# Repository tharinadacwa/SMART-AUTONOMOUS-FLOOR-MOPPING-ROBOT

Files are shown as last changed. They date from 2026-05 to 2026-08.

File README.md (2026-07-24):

<div align="center">

# SAFMR: Smart Autonomous Floor Mopping Robot

### A full-stack autonomous cleaning robot: LiDAR SLAM, Boustrophedon coverage planning, real-time stepper control, and a custom USB-C PD charging board









<br>

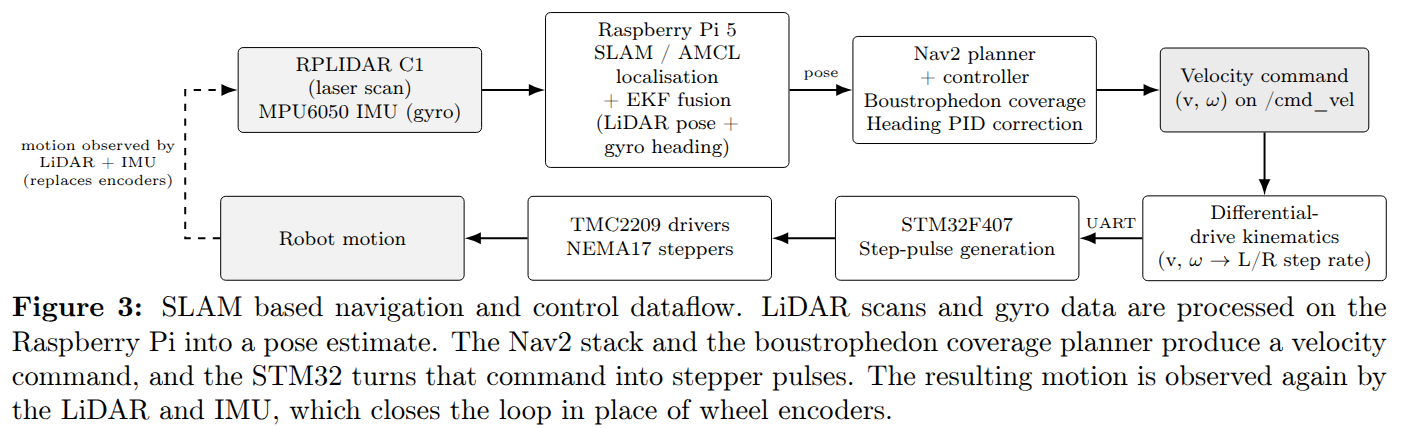
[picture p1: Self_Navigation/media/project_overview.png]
SAFMR system overview


<sub><b>Team MindFlayers</b></sub>

</div>

---

## Table of contents

- [What this is](#what-this-is)
- [The problem we set out to solve](#the-problem-we-set-out-to-solve)
- [System at a glance](#system-at-a-glance)
- [Architecture](#architecture)
- [Repository structure](#repository-structure)
- [Subsystem 1: Navigation and coverage planning](#subsystem-1-navigation-and-coverage-planning)
- [Subsystem 2: Main controller (firmware and PCB)](#subsystem-2-main-controller-firmware-and-pcb)
- [Subsystem 3: Charging sub-system](#subsystem-3-charging-sub-system)
- [The numbers that everything derives from](#the-numbers-that-everything-derives-from)
- [The UART contract](#the-uart-contract)
- [Quick start](#quick-start)
- [Documentation index](#documentation-index)
- [Safety](#safety)
- [Known gaps and things to reconcile](#known-gaps-and-things-to-reconcile)
- [Roadmap](#roadmap)
- [License](#license)

---

## What this is

SAFMR maps a room with LiDAR, plans a provably complete cleaning route across it,
and then sweeps, mops and vacuums that route without anyone pushing it. It is not
a random-bounce consumer robot: every square metre of reachable floor is visited
deliberately, and the robot can report afterwards what it actually cleaned.

The project spans four disciplines and all of them are in this repository:

| Discipline | What we built |
|---|---|
| **Robotics software** | ROS 2 Jazzy stack with Nav2, slam_toolbox, AMCL, EKF fusion, and a Boustrophedon Cellular Decomposition coverage planner written from first principles |
| **Embedded firmware** | STM32F407 real-time motion controller: 40 kHz DDS pulse engine, jerk-limited S-curve profiling, CRC-8 framed serial protocol |
| **Hardware design** | Two Altium boards: the main controller PCB and a USB-C Power Delivery LiPo charger |
| **Systems integration** | A split-brain architecture where the Pi plans and the STM32 actuates, joined by one carefully specified UART link |

| Headline specification | Value |
|---|---|
| Chassis | 45 cm class, 380 mm body disc, 420 mm across the wheels |
| Cleaning head | Dual mopping discs plus sweep brushes, 300 mm swept width |
| Coverage | Complete over reachable drivable area (see [coverage definitions](#known-gaps-and-things-to-reconcile)) |
| Runtime | Approximately 60 minutes per charge |
| Compute | Raspberry Pi 5 (Ubuntu Server 24.04) plus STM32F407VET6 |
| Control | Android app, or ROS 2 service calls |
| Target price | Approximately LKR 200,000 |

---

## The problem we set out to solve

We surveyed 20 facility managers across offices, hospitals and hotels in Sri Lanka:

| Finding | Share |
|---|---|
| Say labour cost and staffing is their single biggest cleaning challenge | 45% |
| Are already looking to buy or rent a commercial cleaning robot | 65% |
| Would consider buying at approximately LKR 200,000 | 95% |
| Rate cutting cleaning labour hours as very important (6 or 7 out of 7) | 80% |
| Say results are inconsistent because it depends who is mopping that day | 35% |
| Say cleaning simply takes too long to get through | 15% |
| Flag staff safety on wet or busy floors | 5% |

Capable autonomous scrubbers already exist, but as imported units priced far out
of reach for most local facilities. That gap is the thing this project targets.

---

## System at a glance

| Layer | Component | Role |
|---|---|---|
| High-level controller | Raspberry Pi 5, Ubuntu Server 24.04 | ROS 2 Jazzy, Nav2, SLAM, coverage planning |
| Low-level controller | STM32F407VET6 | Real-time step generation, motion sequencing, mop and pump control |
| Charger controller | STM32G071CBTx | USB-PD negotiation, BQ25703A charge control, cell balancing |
| LiDAR | RPLIDAR C1 | 2D scanning for SLAM, localisation and obstacle sensing |
| IMU | MPU6050 | Yaw rate for rotation correction |
| Drive | 2 x NEMA-17 42-34 via DRV8825 at 1.4 A, 1/16 microstep | Differential drive, deliberately **encoderless** |
| Cleaning | 4 x brushed DC motors via 2 x L298N, plus a water pump on an IRLZ44N | Mopping discs, sweep brushes, water feed |
| Power | Isolated motor and logic rails, LiPo pack | Motor supply kept off the Pi rail |

### The one design decision that shapes everything

**The robot has no wheel encoders, by choice.** Closed-loop behaviour is recovered
from two independent sources instead:

1. **Translation** comes from verified step counts. The STM32 counts every pulse it
   emits and reports an exact cumulative tally, so distance closes on the commanded
   value rather than on elapsed time.
2. **Rotation** comes from the MPU6050 gyroscope, integrated. Wheel-derived heading
   is explicitly distrusted and is disabled in the EKF, because a single lost step on
   an encoderless drivetrain corrupts the yaw estimate permanently.

That split is why the firmware bothers with jerk-limited S-curve profiling, and why
the EKF configuration deliberately throws away wheel yaw. Both choices exist to
protect an odometry source that has no way to detect its own errors.

---

## Architecture

```mermaid
flowchart TD
    subgraph PI["Raspberry Pi 5 (ROS 2 Jazzy)"]
        SLAM["slam_toolbox<br/><i>online async mapping</i>"]
        AMCL["AMCL<br/><i>localisation on saved map</i>"]
        EKF["robot_localization EKF<br/><i>wheel translation + gyro yaw</i>"]
        COV["coverage_server<br/><i>BCD path playback</i>"]
        NAV["Nav2<br/><i>planner, controller, behaviour trees</i>"]
        HW["ros2_control<br/><i>StepperDiffDrive plugin</i>"]
    end

    subgraph STM["STM32F407VET6"]
        PROTO["Protocol parser<br/><i>CRC-8 framing</i>"]
        MOTION["Motion engine<br/><i>40 kHz DDS + S-curve</i>"]
        DC["Mop motors + pump"]
    end

    LIDAR["RPLIDAR C1"] --> SLAM
    LIDAR --> AMCL
    IMU["MPU6050"] --> EKF
    SLAM --> AMCL
    AMCL --> NAV
    EKF --> NAV
    COV --> NAV
    NAV --> HW
    HW -->|"UART 115200<br/>/dev/ttyAMA0"| PROTO
    PROTO --> MOTION
    MOTION --> DRV["DRV8825 x2"]
    DRV --> MOT["NEMA-17 x2"]
    MOT --> ROBOT["Robot motion"]
    ROBOT -.->|"step tally at 50 Hz"| PROTO
    PROTO -.-> HW
    HW -.-> EKF
```

### The three operating phases

| Phase | When | What happens |
|---|---|---|
| **1. Map** | Once per environment | Drive the robot manually while `slam_toolbox` builds a pose graph, then save with `map_saver_cli` |
| **2. Plan** | Offline, on a laptop | `bcd_coverage.py` cleans the map, runs reachability QA, decomposes it into cells, and freezes a waypoint list plus a preview PNG you actually look at before trusting it |
| **3. Clean** | Every run, on the Pi | `map_server` and AMCL localise, `coverage_server` replays the frozen path through Nav2, the STM32 executes it |

Planning offline is deliberate. The coverage path is reviewed by a human before the
robot is allowed to drive it, which catches unreachable regions and pinched corridors
before they become a robot wedged behind a sofa.

---

## Repository structure

This repository uses **one branch per engineering discipline**, with `main` as the
integrated view containing all of them.

| Branch | Contents |
|---|---|
| **`main`** | Everything below, integrated. Start here. |
| `Self_Navigation` | ROS 2 workspace, coverage planner, SLAM and Nav2 configuration |
| `Firmware_Design` | STM32F407 main controller firmware |
| `PCB_Design` | Altium hardware for the main controller board |
| `Hardware_Integration` | Wiring, assembly and integration work |
| `3D_Design` | Mechanical CAD for the chassis and cleaning head |

```
SAFMR/
├── Self_Navigation/                  ROS 2 Jazzy stack and coverage planner
│   ├── bcd_coverage.py            standalone BCD planner (offline)
│   ├── robot.yaml                 SINGLE SOURCE OF TRUTH for physical parameters
│   ├── tools/generate_config.py   regenerates every derived config from robot.yaml
│   ├── ros2_ws/src/
│   │   ├── minibot_bringup/       launch files, controllers, udev, systemd
│   │   ├── minibot_coverage/      coverage server and map preparation
│   │   ├── minibot_description/   URDF, xacro, RViz layouts
│   │   ├── minibot_hardware/      ros2_control StepperDiffDrive plugin (C++)
│   │   ├── minibot_imu/           MPU6050 node, calibration, EKF config
│   │   └── minibot_navigation/    Nav2 params, behaviour trees, keepout filters
│   ├── robot_files/               bring-up scripts used before the plugin existed
│   ├── maps/                      saved occupancy grids
│   ├── media/                     demonstration images and GIFs
│   └── docs/                      six deep-dive documents (see index below)
│
├── MAIN_CONTROLLER/             STM32F407 firmware and main PCB
│   ├── README.md                  full firmware documentation
│   ├── firmware_Main/minibot_fw/  CubeIDE project, HAL drivers, wiring guides
│   └── SFAMR_MainPCB/             Altium schematic, PCB layout, libraries
│
├── Charging_Sub_System/         USB-C PD LiPo charger
│   ├── README.md                  charger documentation
│   ├── EDR_LIPO/                  Altium hardware, 3D renders, board photos
│   └── edr_Lipo_1v1/              STM32G0 firmware: UCPD, BQ25703A, balancing
│
├── MIND FLAYERS project pitch.pdf
├── LICENSE                      GNU GPL v3
└── README.md                    this file
```

---

## Subsystem 1: Navigation and coverage planning

> Full documentation: [`Self_Navigation/README.md`](Self_Navigation/README.md)

<div align="center">
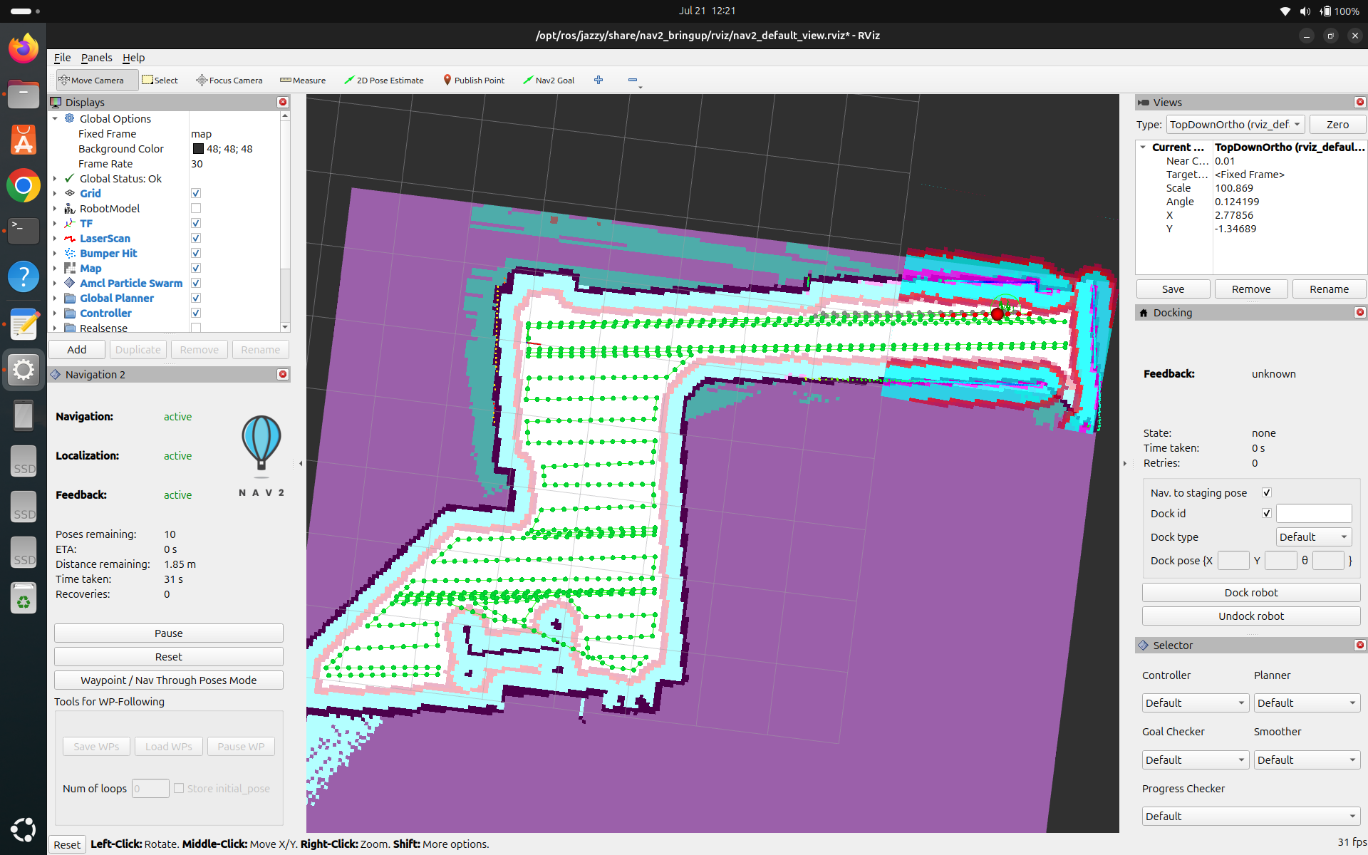
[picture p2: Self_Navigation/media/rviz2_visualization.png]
RViz2 navigation view with coverage waypoints

<br><sub>RViz2: map, costmaps, TF tree and colour-coded coverage waypoints</sub>
</div>

### Boustrophedon Cellular Decomposition

*Boustrophedon* is Greek for "as the ox turns while ploughing", which is exactly the
back-and-forth motion the planner produces. The classic formulation is due to Choset.

**How it works.** A vertical sweep line passes across the map one pixel column at a
time, counting connected free slices in that column. When the count changes, an
obstacle has started or ended, and that column is a *critical point*. A slice count
increase is an IN event that splits the current cell; a decrease is an OUT event that
merges and closes cells. Each resulting cell is obstacle-free by construction, so
covering it reduces to sweeping parallel lanes.

**Why decompose at all.** A room with obstacles is not a rectangle. A single sweep
pattern would either clip obstacles or leave gaps. Decomposition turns a hard problem
into many trivial ones.

**Why zig-zag rather than return-to-start.** Entering each lane from the side you
finished on removes the return trip, which would otherwise nearly double travel
distance, and confines turns to lane ends.

| Criterion | Random bounce | BCD |
|---|---|---|
| Coverage guarantee | Probabilistic | Complete over reachable space |
| Overlap | Uncontrolled | Fixed by lane spacing |
| Runtime | Long and variable | Predictable, estimated before running |
| Repeatability | Different every run | Deterministic |
| Progress reporting | Not possible | Per-waypoint |

**Implementation details that matter:**

- Free space is eroded by robot radius plus safety margin, so the planned path is a
  valid **centre** trajectory rather than a wish.
- Unknown map cells are treated as blocked, so the planner never routes into unmapped
  space.
- Only the connected component reachable from the start pose is planned.
- Hairline gaps in walls are sealed morphologically so lanes cannot leak into the next
  room through a one-pixel crack.
- A **Hough transform finds the dominant wall angle** and the map is rotated so lanes
  run parallel to the walls, not to the image axes.

<div align="center">
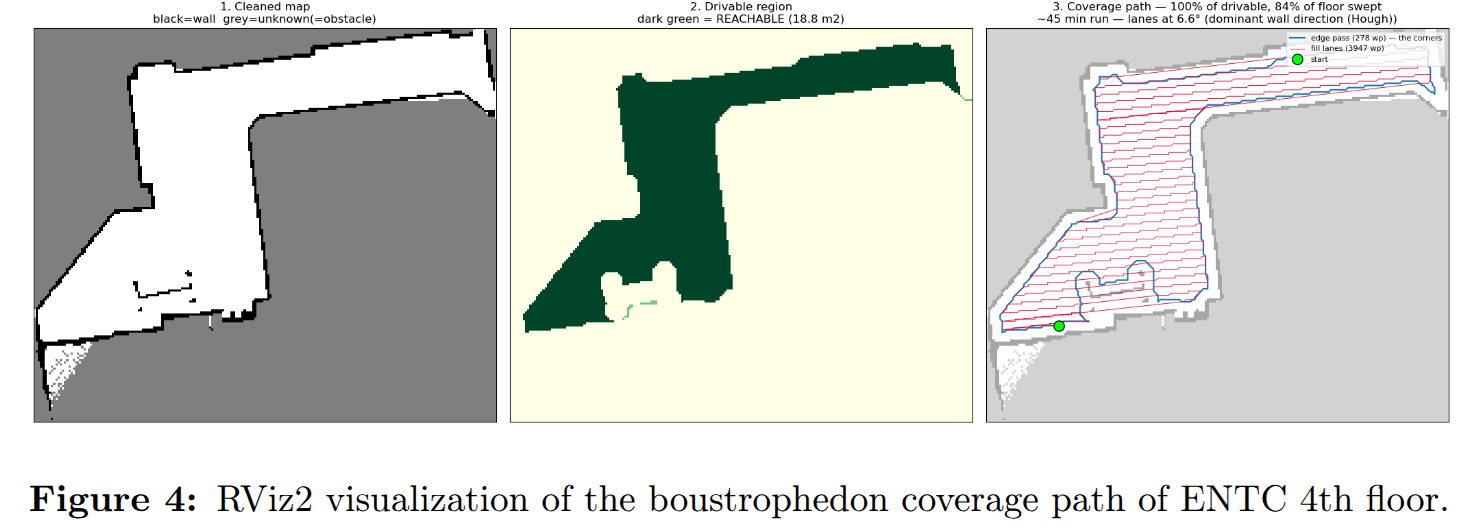
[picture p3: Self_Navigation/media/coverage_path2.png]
BCD coverage path over a saved map

<br><sub>A generated coverage path: edge pass plus serpentine fill</sub>
</div>

### Software stack

| Layer | Technology |
|---|---|
| Middleware | ROS 2 Jazzy |
| Navigation | Navigation2 (NavFn planner, Regulated Pure Pursuit controller) |
| SLAM | slam_toolbox, online asynchronous |
| Localisation | AMCL |
| Fusion | robot_localization EKF, wheel yaw deliberately excluded |
| Hardware interface | ros2_control C++ plugin, `StepperDiffDrive` |
| Coverage planner | Python, OpenCV, NumPy, SciPy |
| Visualisation | RViz2 with live coverage progress markers |

### Deployment

Headless operation is handled by `udev` rules for stable device naming and `systemd`
units for auto-start, both in `minibot_bringup`.

---

## Subsystem 2: Main controller (firmware and PCB)

> Full documentation: [`MAIN_CONTROLLER/README.md`](MAIN_CONTROLLER/README.md)

The STM32F407VET6 owns four independent jobs:

| Subsystem | Hardware | Control |
|---|---|---|
| **Drive** | 2 x stepper via DRV8825 | 40 kHz DDS pulse engine, jerk-limited S-curve, commanded over UART |
| **Mopping** | 4 x brushed DC via 2 x L298N | Fixed direction, running from boot, no speed control |
| **Water pump** | IRLZ44N low-side MOSFET | Free-running timer, 3 s on and 5 s off |
| **Host link** | USART1 to the Pi | CRC-8 framed ASCII, 50 Hz odometry feedback |

### Why the motion engine is built the way it is

**Direct digital synthesis for step timing.** A 32-bit phase accumulator per motor is
incremented every 40 kHz tick; a wrap past 2^32 emits one step pulse and increments the
step counter in the same operation. That coupling is the reason reported odometry is a
tally rather than an estimate. Because the accumulator increment stays below 0.5 for any
rate under 20 kHz, two pulses can never land on consecutive ticks, so the minimum low
time is guaranteed by arithmetic rather than by luck. At the configured 1066 sps ceiling
the engine runs at 5.3% of that limit.

**Jerk limiting is not a nicety.** A trapezoidal ramp steps acceleration discontinuously
from zero to maximum, which is a torque step, which is exactly the impulse that makes a
stepper skip. This robot reverses direction at the end of every lane, roughly 34 times
per room, with no encoder to notice a skipped step. The S-curve is what keeps odometry
honest across a full run.

**Interrupt priority is deliberate.** TIM7 sits at priority 0, above USART1 at 1. The
step ISR takes about 2 microseconds and a UART byte arrives every 87 microseconds at
115200 baud, so the UART is serviced roughly 2 microseconds late in the worst case, well
inside its deadline. Giving the UART top priority instead would trade a problem you do
not have for one you cannot detect.

### Safety behaviour

| Mechanism | Behaviour |
|---|---|
| Boot order | GPIO init runs first and drives `nENABLE` high, so the steppers are dead before anything can twitch |
| Comms watchdog | No command for 500 ms triggers a ramp to stop while staying energised, keeping holding torque so the robot cannot roll on a slope |
| Idle disable | No command for 10 s drops the coils, because a stationary stepper at full current is a 10 W heater doing no work |
| Emergency stop | Bypasses the profile entirely; losing steps is an acceptable trade for stopping now |
| Fault handlers | HardFault, BusFault and UsageFault kill the steppers and the mop motors, then hang |
| UART overrun recovery | An unhandled overrun error silently kills reception forever, so the error ISR clears every flag and re-arms |

### Hardware

The main controller PCB was designed in Altium and lives in
[`MAIN_CONTROLLER/SFAMR_MainPCB/`](MAIN_CONTROLLER/SFAMR_MainPCB), alongside the
schematic, layout and custom footprint libraries.

---

## Subsystem 3: Charging sub-system

> Full documentation: [`Charging_Sub_System/README.md`](Charging_Sub_System/README.md)

<div align="center">
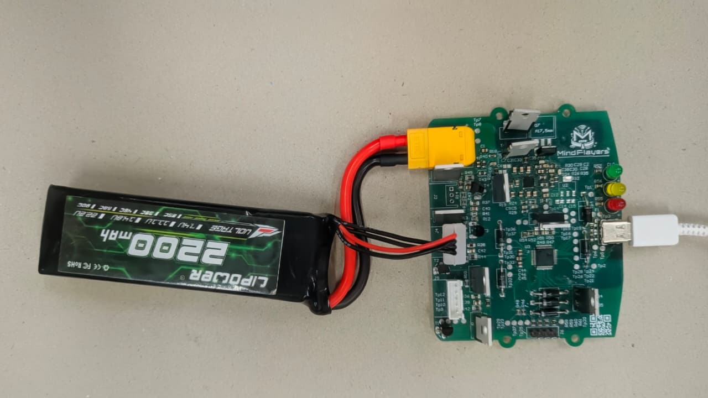
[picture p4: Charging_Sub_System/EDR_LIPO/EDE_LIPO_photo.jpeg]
Assembled and bench-tested charging board

<br><sub>Assembled, populated and bench-tested charging board</sub>
</div>

A USB Type-C Power Delivery charger that negotiates a supply voltage, then charges and
balances the onboard LiPo pack through a TI BQ25703A programmable buck-boost controller
supervised by an STM32G071. Per-cell voltages are read through the MCU ADC and passive
balancing keeps the pack matched during charge. The design is adapted from the
open-source LiPow charger.

| Parameter | Value |
|---|---|
| MCU | STM32G071CBTx, Cortex-M0+ at up to 64 MHz, 128 KB flash, 36 KB SRAM |
| RTOS | FreeRTOS |
| USB-PD stack | UCPD peripheral plus ST X-CUBE-USBPD |
| Charge controller | TI BQ25703A buck-boost over I2C |
| Charge algorithm | CC/CV |
| Supported packs | 1S to 3S |
| Connectors | USB-C in, XT60 out, JST-XH balance |
| Status | Assembled and bench-tested |

Protection thresholds, cell voltage limits and the over-temperature cutoff are
documented in the subsystem README and defined in `edr_Lipo_1v1/Core/Inc/battery.h`.

> **Never charge LiPo cells unattended.** These thresholds protect the pack but are not
> a substitute for a proper BMS.

---

## The numbers that everything derives from

[`Self_Navigation/robot.yaml`](Self_Navigation/robot.yaml) is the single source of truth. Running
`python3 Self_Navigation/tools/generate_config.py` regenerates every derived configuration
from it.

This matters because the same physical constants live in **five** places: the STM32
firmware, ros2_control, the Nav2 controller server, the Nav2 velocity smoother, and the
coverage planner. If any two disagree, the strictest layer silently clips the others,
and the planner then believes the robot went somewhere it did not.

### Measured geometry

| Quantity | Value | Note |
|---|---|---|
| Wheel diameter | 67.2 mm | Measure it **loaded**; rubber compresses about 1 mm, which is a 3% odometry error |
| Wheel radius | 0.0336 m | |
| Wheel separation | 0.400 m | Centre-to-centre of contact patches |
| Wheel outer span | 0.410 to 0.420 m | |
| `robot_radius` | **0.210 m** | Half the **wheel** span, not half the body |
| Body diameter | 0.380 m | Narrower than the wheels |
| LiDAR height | 0.250 m from ground | |
| Robot mass | about 6 kg | |

**The wheels are the widest part of the robot.** Nav2 plans against 0.210 m. Plan
against the body radius instead and Nav2 will confidently drive the wheels into walls
it believes the body clears, which presents as "the robot keeps scraping along walls"
and looks like a controller bug.

### Kinematic envelope

| Quantity | Value |
|---|---|
| Steps per wheel revolution | 3200 (200 steps x 16 microstep) |
| Distance per step | **0.066 mm**, your odometry resolution |
| Linear velocity | 0.0176 to 0.0704 m/s |
| Angular velocity | 0.088 to 0.352 rad/s |
| 180 degree spin in place | 8.93 s |
| Step rate cap | 1066 sps, which is 5.3% of the pulse engine |

### Two limits worth understanding

**The 20 RPM cap is the single biggest cost in the project.** At 20 RPM the pulse
engine is 5.3% used and the motors carry roughly 12x torque margin at 6 kg. Raising it
is one number in `robot.yaml` followed by a regeneration:

| RPM | Speed | Step rate | Pulse engine used | 49 m^2 flat |
|---|---|---|---|---|
| 20 | 0.070 m/s | 1066 sps | 5.3% | about 95 min |
| 40 | 0.141 m/s | 2133 sps | 10.7% | about 47 min |
| 60 | 0.211 m/s | 3200 sps | 16.0% | about 31 min |
| 100 | 0.352 m/s | 5333 sps | 26.7% | about 19 min |

**The 9 cm wall strip is mechanical, not a software bug.** The robot centre cannot get
closer to a wall than `robot_radius` plus `safety_margin` (0.210 + 0.030 = 0.240 m), and
the brush span reaches only 0.150 m from centre, so the brush stops 9 cm short of every
wall. No planner fixes this. The options are to accept it, drop the safety margin to
0.01 for a 7 cm strip at the cost of wall clearance, or mount the brushes further
outboard, which is the real fix.

---

## The UART contract

One serial link joins the two halves of the robot, so its specification is the most
important interface in the project.

```
$<PAYLOAD>*<CRC8_HEX><LF>
```

CRC-8/ATM, polynomial `0x07`, init `0x00`, no reflection, no final XOR, computed over
the payload only. A `$` always restarts the parser, which is what lets it resynchronise
after line noise.

### Pi to STM32

| Frame | Meaning |
|---|---|
| `$V,<left_sps>,<right_sps>*XX` | Signed step-rate target; also enables drivers and clears E-stop |
| `$E,<0 or 1>*XX` | Enable or disable the stepper drivers |
| `$S*BE` | Emergency stop, bypasses the ramp |
| `$R*B9` | Reset step counters |
| `$P*B7` | Ping, answered with `$K*F6` |

### STM32 to Pi, at 50 Hz

```
$F,<l_steps>,<r_steps>,<l_sps>,<r_sps>,<flags>,<seq>*XX
```

The cumulative signed step counts are the odometry. The sequence number lets the host
detect dropped frames rather than silently interpolating across them. Flags report
enabled, E-stop, command timeout, CRC error, UART overrun and rate clamping.

**Why CRC-8 and not a checksum.** The motor wires running alongside this cable switch
amps at kilohertz rates. One flipped bit in a velocity command is a robot driving into a
wall. CRC-8 catches all single-bit errors, all double-bit errors, and all burst errors up
to 8 bits. A sum or an XOR does not.

---

## Quick start

### Prerequisites

| Where | What |
|---|---|
| Raspberry Pi 5 | Ubuntu Server 24.04, ROS 2 Jazzy, Nav2, slam_toolbox, robot_localization |
| Laptop | Python 3.12 with OpenCV, NumPy, SciPy for offline planning |
| Firmware | STM32CubeIDE, or `arm-none-eabi-gcc` 13.2.1 with `stlink-tools` |
| Hardware CAD | Altium Designer |

### 1. Flash the main controller

```bash
cd MAIN_CONTROLLER/firmware_Main/minibot_fw
make
make flash
```

Before the first flash, confirm your crystal is 8 MHz. Many F407VET6 boards ship with
25 MHz, and if yours does, both the baud rate and the step rate are wrong by the same
25/8 ratio. The firmware README documents the two-line fix.

### 2. Set up the Pi

```bash
cd Navigation
bash tools/setup_pi.sh
cd ros2_ws && colcon build --symlink-install
source install/setup.bash
```

### 3. Map the room

```bash
ros2 launch minibot_bringup robot.launch.py
ros2 launch minibot_bringup map.launch.py
# drive it around with teleop, then:
ros2 run nav2_map_server map_saver_cli -f maps/home
```

### 4. Plan coverage offline

```bash
python3 bcd_coverage.py maps/home.yaml --out home_coverage_path.yaml
```

This also writes a QA report and a preview PNG. **Look at the preview before running
it.** The QA report flags unreachable regions, narrow corridors and the estimated run
time.

### 5. Clean

```bash
ros2 launch minibot_bringup clean.launch.py map:=maps/home.yaml \
     path:=home_coverage_path.yaml
ros2 service call /coverage/start std_srvs/srv/Trigger
```

`auto_start` is deliberately false. Confirm AMCL has converged in RViz before starting
the run.

Runtime control is exposed as services: `/coverage/start`, `/coverage/stop` (resumable,
the checkpoint is kept), `/coverage/skip` for when the robot is wedged, and
`/coverage/dock`.

---

## Documentation index

| Document | Covers |
|---|---|
| [`Self_Navigation/README.md`](Self_Navigation/README.md) | Coverage planning, SLAM, the full ROS 2 stack, file-by-file manifest |
| [`Self_Navigation/docs/ARCHITECTURE.md`](Self_Navigation/docs/ARCHITECTURE.md) | Node graph, the three phases, TF ownership |
| [`Self_Navigation/docs/HARDWARE.md`](Self_Navigation/docs/HARDWARE.md) | Measured geometry, wiring, the wall-strip and brush-gap analyses |
| [`Self_Navigation/docs/INTERFACES.md`](Self_Navigation/docs/INTERFACES.md) | Every topic, service, action, TF frame and UART packet |
| [`Self_Navigation/docs/DERIVED_NUMBERS.md`](Self_Navigation/docs/DERIVED_NUMBERS.md) | How every velocity and limit is derived, plus the Revision 2 correction |
| [`Self_Navigation/docs/TESTING.md`](Self_Navigation/docs/TESTING.md) | Verification procedure |
| [`Self_Navigation/docs/REVISION_2.md`](Self_Navigation/docs/REVISION_2.md) | What changed when the hardware was actually measured |
| [`MAIN_CONTROLLER/README.md`](MAIN_CONTROLLER/README.md) | Firmware architecture, pin map, protocol, bring-up checklist, troubleshooting |
| [`Charging_Sub_System/README.md`](Charging_Sub_System/README.md) | Charger hardware, firmware, protection thresholds |

### A note on Revision 2

Revision 1 of this project used a wheel radius of 0.19 m and a wheel separation of
0.30 m. Both were wrong. The real figures are 0.0336 m and 0.400 m, meaning the wheel
radius was off by a factor of 5.65 and every velocity, every Nav2 threshold and the
entire URDF were wrong with it. `docs/REVISION_2.md` documents the correction. We have
left that history in the repository deliberately, because the failure mode is instructive:
nothing crashed, nothing threw an error, the robot simply believed it had travelled
distances it had not.

---

## Safety

**Read before powering the robot for the first time.**

At power-on with no host connected, the stepper drivers stay disabled, but **the four
mop motors start immediately** and the water pump begins cycling. Both are open-loop and
run from boot with no host command and no way to stop them over the serial link. On a
workbench, comment out `DCM_Run()` and the pump task before the first power-up.

**Common ground is mandatory.** The STM32 ground, both L298N ground terminals, the
MOSFET source and the battery negative must all be one node. A missing common ground is
the single most frequent cause of "the motors behave randomly".

**Verify microstepping before trusting any distance.** If the DRV8825 jumpers are
actually 1/8, or the motors are 0.9 degrees per step, every distance is silently double
what the robot thinks and nothing in the system will tell you. The firmware README
includes a step-verification procedure.

**Never charge LiPo cells unattended.**

---

## Known gaps and things to reconcile

Documented honestly, because a project this size accumulates loose ends and the next
person should not have to find them the hard way.

**Two different coverage figures are quoted.** The project pitch says approximately 94%
coverage. The QA report from a real map run reports 100% of *reachable drivable area*
and 80.8% of *total floor swept by the body*. These measure different things and both are
defensible, but the repository should state which definition it means wherever a
percentage appears.

**Chassis dimension inconsistency.** The pitch describes a 45 cm chassis; `robot.yaml`
records a 380 mm body with a 410 to 420 mm wheel span. Worth reconciling to one number
before submission.

**Lane spacing disagreement.** `robot.yaml` sets `lane_spacing: 0.19` against a 0.30 m
cleaning head, which is 11 cm of overlap on every pass, or 37% of the floor cleaned
twice. The QA report was generated at 0.25 m, which still leaves 5 cm of overlap and cuts
run time by roughly a quarter. The value was kept at 0.19 because it was specified, but
it is worth a deliberate decision rather than an inherited one.

**The 100 mm gap between the brushes needs confirming.** Two 100 mm brushes with centres
200 mm apart leave a 100 mm gap down the middle. That is fine if the suction inlet sits
there, which is the standard design, but if nothing is in the middle then there is an
uncleaned stripe down the centre of every lane, and the "percent swept" readout is
overstating reality.

**Unverified constants.** `motor_holding_torque_nm` is a typical NEMA-17 figure rather
than a reading from the motor label, and `imu_height_from_ground` is an estimate. The
torque margin claim depends on the first of these.

**Cross-subsystem documentation links are broken after the reorganisation.**
`MAIN_CONTROLLER/README.md` links to `WIRING_L298N.md` and `WIRING_PA12_PUMP.md` as
siblings, but those files live in `firmware_Main/minibot_fw/`. `Self_Navigation/README.md`
still references an `stm32/` folder that has been removed from that branch in favour of
`MAIN_CONTROLLER/`. Both need their paths updated.

**The firmware README overstates what is missing.** It lists `robot.yaml`,
`tools/generate_config.py` and `stm32_bench.py` as absent. All three exist, in
`Self_Navigation/`. That note was written before the branches were integrated and should now
be replaced with cross-references.

**Build artifacts are committed.** `MAIN_CONTROLLER/firmware_Main/minibot_fw/Debug/`
holds roughly 30 MB of object files, ELF, map and listing output that gets regenerated
on every build.

**No PWM speed control for the mop motors.** All eight available pins are used as L298N
direction inputs, so the enable pins are hard-tied high. Speed control needs two more
pins on a timer output.

**Mop motors and pump are not host-controllable.** They need protocol commands wired to
`DCM_Set()` and the pump timer before the Pi can start or stop cleaning independently of
driving.

---

## Roadmap

| Area | Planned work |
|---|---|
| Obstacle handling | Adaptive avoidance of dynamic obstacles mid-sweep |
| Replanning | Online re-decomposition when the map changes during a run |
| Multi-room | Room segmentation and inter-room sequencing |
| Energy | Battery-aware planning with resume from the last waypoint |
| Vision | Camera integration for dirt and surface detection |
| AI | Object detection to classify and avoid hazards |
| Telemetry | Cloud monitoring of coverage reports |
| Motion | Raise the RPM cap and re-verify, which is the cheapest available win |

---

## License

Copyright (c) 2026 Team MindFlayers.

This project is licensed under the **GNU General Public License v3.0**. See
[`LICENSE`](LICENSE) for the full text. You are free to use, study, modify and share it
under the same license.

Third-party components retain their own licenses:

| Component | License |
|---|---|
| STM32 HAL and CMSIS under `Drivers/` | ST and ARM licenses, see the license files in those directories |
| ROS 2, Nav2, slam_toolbox, robot_localization | Apache 2.0 and BSD, per upstream |
| LiPow charger reference design | Per the upstream LiPow project |

---

<div align="center">

**Team MindFlayers**

<sub>Built for institutions that are done paying, every single day, for someone to clean the same square metre of floor.</sub>

</div>

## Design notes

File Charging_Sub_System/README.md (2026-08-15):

<div align="center">

#  🔋 Charging Sub-System

### LiPo charging hardware and firmware for the Smart Autonomous Floor Mopping Robot

A USB-C Power Delivery charger that charges and balances the robot's onboard
LiPo pack - built around an STM32G0 MCU and a TI BQ25703A buck-boost charger.

</div>

<br>

<div align="center">
  Assembled and tested EDR_LIPO charging board
  <br>
  <em>Assembled, populated, and bench-tested charging board</em>
</div>

<br>

<div align="center">
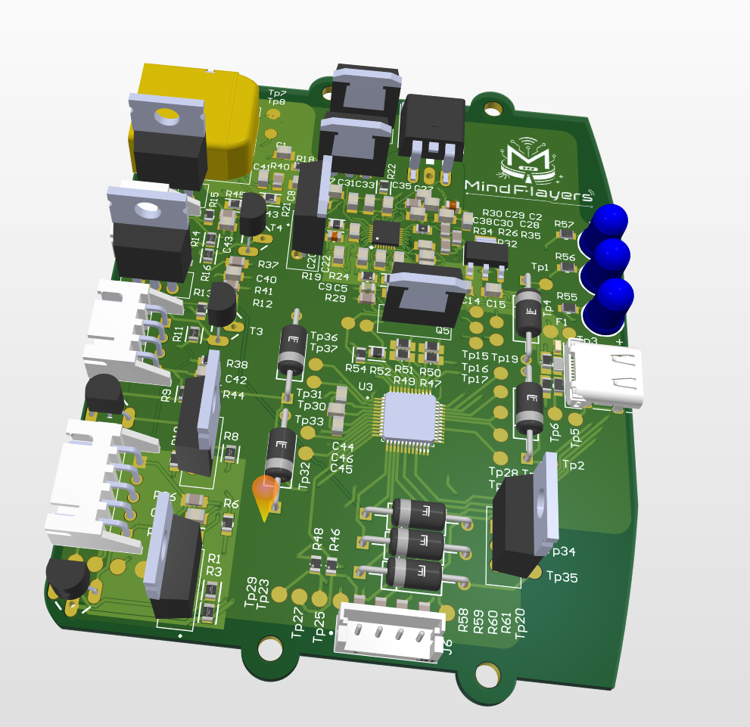
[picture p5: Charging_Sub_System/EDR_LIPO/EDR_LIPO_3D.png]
Altium 3D render
  
  <br>
  <em>3D view - Altium render</em>
</div>

<br>

<div align="center">
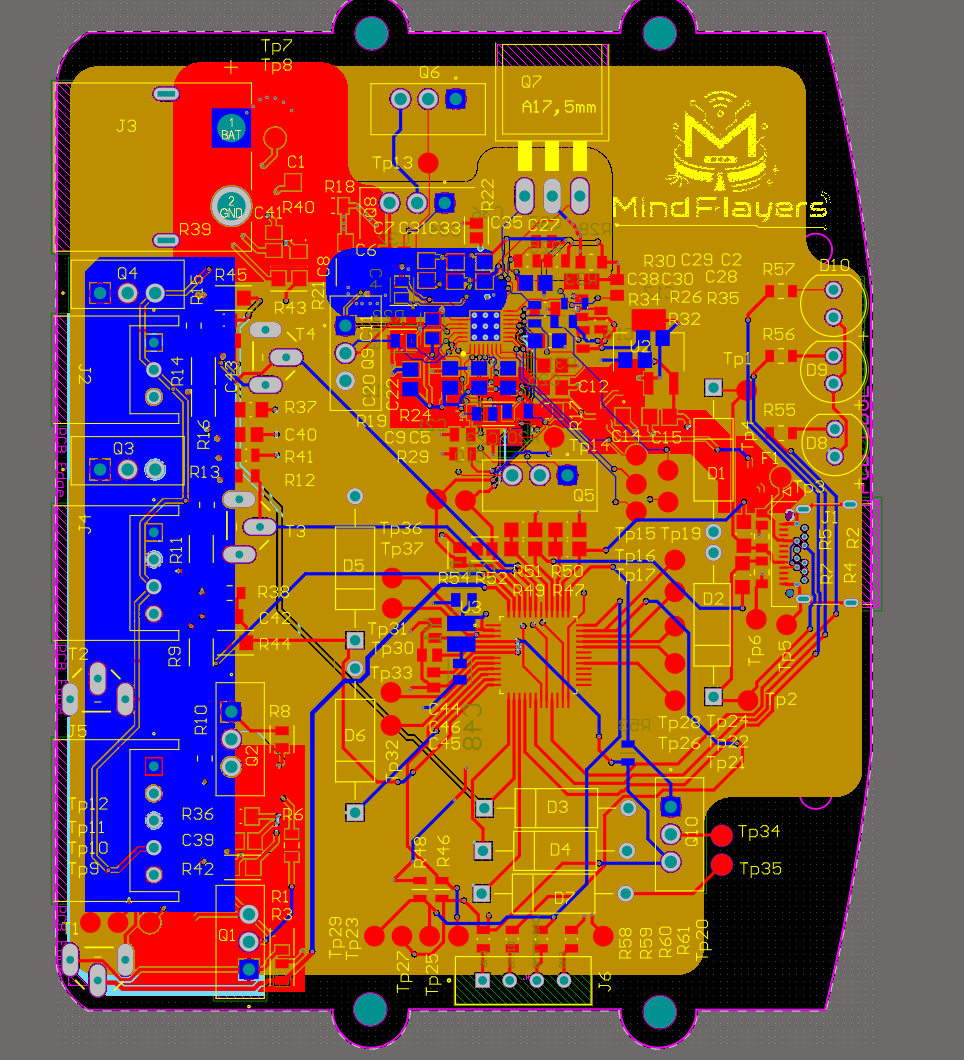
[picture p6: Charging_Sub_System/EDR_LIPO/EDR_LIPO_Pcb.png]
PCB layout, all layers
  
  <br>
  <em>PCB layout - all layers active</em>
</div>

---

## Overview

This sub-system takes power from a USB Type-C PD source, negotiates a supply
voltage, and charges a multi-cell lithium-polymer pack through a TI BQ25703A
programmable buck-boost charge controller supervised by an STM32G0. Per-cell
voltages are read through the MCU's ADC, and passive balancing keeps the pack
matched during charge. The design is adapted from the open-source LiPow charger.

It is split into two parts - the **hardware** (Altium PCB) and the **firmware**
(STM32G0) - each documented in its own folder.

## Contents

| Folder | Description |
|---|---|
| **[`EDR_LIPO/`](EDR_LIPO)** | Hardware - Altium schematics, PCB layout, renders, and board photos for the LiPo charging board |
| **[`edr_Lipo_1v1/`](edr_Lipo_1v1)** | Firmware (v1.1) - STM32G0 project: USB-PD negotiation, BQ25703A charge control, and cell balancing |

## Technical Specifications

### System

| Parameter | Value |
|---|---|
| Function | USB-C PD LiPo battery charger and balancer |
| Charge algorithm | CC/CV via TI BQ25703A |
| CAD tool | Altium Designer |
| Firmware version | v1.1 |
| Board status | Assembled and bench-tested |

### Microcontroller

| Parameter | Value |
|---|---|
| MCU | STM32G071CBTx |
| Core | Arm Cortex-M0+ @ up to 64 MHz |
| Flash / SRAM | 128 KB / 36 KB |
| Package | LQFP48 |
| RTOS | FreeRTOS |
| USB-PD stack | UCPD peripheral + ST X-CUBE-USBPD |

### Power & charging

| Parameter | Value |
|---|---|
| Input connector  | USB Type-C |
| Input protocol | USB Power Delivery (sink) |
| PD current requested | Up to 3 A *(firmware PDO configuration)* |
| Charge controller | TI BQ25703A buck-boost, over I²C |
| Charge output | XT60 connector |
| Balance connector | JST-XH |
| Supported packs | 1S – 4S *(per firmware cell-count bitmasks)* |
| Cell monitoring | STM32G0 ADC via resistor dividers |
| Balancing | Passive, per-cell *(LiPow reference: PFET discharge)* |
| Max power *(reference)* | Up to 100 W / 6 A - *LiPow reference; verify for this build* |

### Interfaces

| Interface | Use |
|---|---|
| I²C | STM32G0 → BQ25703A charge controller |
| UART | Debug / command-line interface |
| SWD | Programming and debug |
| RGB LED  | Charge / balance status feedback |

### Protection thresholds

From the firmware (`edr_Lipo_1v1/Core/Inc/battery.h`). Verify against your pack
chemistry before connecting a real battery.

| Condition | Value |
|---|---|
| Start charging (per cell below) | 4.18 V |
| Begin balancing discharge (per cell above) | 4.205 V |
| Stop charging - over-voltage (per cell above) | 4.22 V |
| Minimum cell for balancing | 3.0 V |
| Absolute minimum safe cell voltage | 2.0 V |
| Enable balancing when cell delta exceeds | 15 mV (10 mV hysteresis) |
| MCU over-temp cutoff / recovery | 75 °C / 65 °C |

> Values in *italics* come from the LiPow reference design rather than a confirmed
> reading of this board. These limits protect the pack but are not a substitute for
> a proper BMS - never charge LiPo cells unattended.

---

## License

Copyright © 2026 **@tharinadacwa**.

This project is licensed under the **GNU General Public License v3.0** - see the
[`LICENSE`](LICENSE) file for the full text. You are free to use, study, modify,
and share it under the same license.

<div align="center">
<br>
<sub>Board revision, firmware port, integration and testing for the Smart Autonomous Floor Mopping Robot by <b>@tharinadacwa</b></sub>
</div>

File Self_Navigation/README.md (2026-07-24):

<div align="center">

# 🧹 Smart Autonomous Floor Mopping Robot

### Autonomous coverage cleaning using ROS 2, LiDAR SLAM and Boustrophedon Cellular Decomposition










<br>

<!-- 📸 Replace with the robot / system overview image -->

</div>

---

## 📌 Overview

**The problem**

- 🔁 Consumer cleaning robots often rely on random-bounce motion, so floor area is covered unevenly and repeatedly.
- ⏱️ Random motion needs several times longer to approach full coverage of the same room.
- 🚫 Without a global map, the robot cannot report what it actually cleaned.

**Why coverage path planning matters**

- ✅ Guarantees every reachable cell of the floor is visited **at least once**.
- ✅ Minimises overlap, which directly reduces runtime and battery use.
- ✅ Produces a deterministic, repeatable and auditable cleaning route.

**What makes this project different**

| | |
|---|---|
| 🧭 | Full **Boustrophedon Cellular Decomposition (BCD)** planner written from scratch, not an off-the-shelf coverage plugin |
| ⚙️ | **Encoderless closed-loop motion control** using STM32 step verification plus MPU6050 yaw integration |
| 🗺️ | Lanes are aligned to the **dominant wall direction** via Hough transform, not to the image axes |
| 🧱 | Complete split-brain architecture: Raspberry Pi for planning, STM32 for real-time actuation |

---

## 🔧 Hardware Architecture

| Component | Model | Role |
|---|---|---|
| 🧠 High-level controller | **Raspberry Pi 5** (Ubuntu Server 24.04) | ROS 2 Jazzy, Nav2, SLAM, coverage planning |
| ⚡ Low-level controller | **STM32F407** | Real-time step generation and motion sequencing |
| 📡 LiDAR | **RPLIDAR C1** | 2D scanning for SLAM, localisation and obstacle sensing |
| 🧭 IMU | **MPU6050** | Yaw rate for rotation correction |
| 🔩 Actuators | **2 × NEMA17 stepper motors** | Differential drive, **no wheel encoders** |
| 🔌 Drivers | **DRV8825** | Microstepping current control |
| 🔋 Power | Isolated motor and logic rails | Motor supply kept off the Pi rail |

**Division of responsibility**

- ✔️ **Raspberry Pi** performs high-level navigation and all ROS 2 computation.
- ✔️ **STM32** performs real-time motor control over a UART link (`/dev/ttyAMA0`).
- ✔️ **RPLIDAR C1** performs SLAM and localisation.
- ✔️ **MPU6050** provides yaw rate for heading feedback.
- ✔️ **NEMA17 motors are encoderless**, so closed-loop behaviour is recovered in firmware.

<div align="center">

<!-- 📸 Replace with the SLAM / system architecture image -->
System architecture

</div>
<div align="center">

<!-- 🎞️ Robot following the coverage path -->
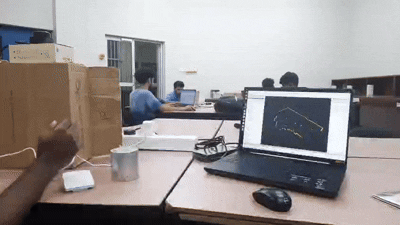
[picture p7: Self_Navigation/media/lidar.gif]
RPLidar C1


<sub>Visualization of boundaries and obstacles with RPLidar C1</sub>

</div>

---

## 💻 Software Stack

| Layer | Technology | Purpose |
|---|---|---|
| 🤖 Middleware | **ROS 2 Jazzy** | Node graph, TF tree, message transport |
| 🧭 Navigation | **Navigation2** | Global and local planning, controller server, behaviour trees |
| 🗺️ SLAM | **slam_toolbox** | Online async mapping and pose graph optimisation |
| 📍 Localisation | **AMCL** | Particle filter localisation against the saved map |
| 🔗 Fusion | **robot_localization (EKF)** | Fuses wheel translation with MPU6050 yaw |
| ⚙️ Hardware interface | **ros2_control** (C++) | `StepperDiffDrive` plugin, UART protocol to STM32 |
| 🧮 Coverage planner | **Python + OpenCV + NumPy + SciPy** | BCD decomposition, Hough wall alignment, path export |
| 👁️ Visualisation | **RViz2** | Map, costmaps, TF, live coverage waypoint markers |
| 🔬 Firmware | **STM32 HAL / C** | Timer-driven step pulses, protocol parser, motion queue |

---

## 🧭 Boustrophedon Cellular Decomposition

> *Boustrophedon* is Greek for "as the ox turns while ploughing", which is exactly the back-and-forth motion the planner produces.

**What BCD is**

- A coverage algorithm that divides free space into obstacle-free **cells**, then sweeps each cell with parallel lanes.
- Classic formulation by Choset, widely used for cleaning, agricultural and inspection robots.

**Why decompose at all**

- 🧩 A room with obstacles is **not** a simple rectangle, so a single sweep pattern would either clip obstacles or leave gaps.
- 🧩 Each cell **is** obstacle free by construction, so inside a cell coverage becomes trivial.

**Why obstacles split the environment**

- A vertical sweep line is passed across the map one pixel column at a time.
- The number of connected free **slices** in that column is counted.
- When that count changes, an obstacle has started or ended. That column is a **critical point**.
- 🔻 Slice count increases → **IN event** → the current cell splits into new cells.
- 🔺 Slice count decreases → **OUT event** → cells merge and are closed.

**How cells are covered**

1. Lanes are spaced by the mop width minus a small overlap.
2. Within a cell the robot drives to one end of a lane, then the other.
3. The next lane is entered from the side it finished on, giving the zig-zag.
4. Cells are visited in sweep order so the transition between cells is short.

**Why zig-zag**

- ➡️ Removes the need to return to a start point after each lane, which would nearly double travel distance.
- ➡️ Turns occur only at lane ends, so the number of rotations is minimal.
- ➡️ Repeated cleaning is bounded to the deliberate lane overlap only.

**Advantages over random coverage**

| Criterion | Random bounce | BCD |
|---|---|---|
| Coverage guarantee | ❌ Probabilistic | ✅ Complete over reachable space |
| Overlap | ❌ Uncontrolled | ✅ Fixed by lane spacing |
| Runtime | ❌ Long and variable | ✅ Predictable, estimated before running |
| Repeatability | ❌ Different every run | ✅ Deterministic |
| Reporting | ❌ Not possible | ✅ Waypoint level progress |

**Implementation notes**

- Free space is eroded by robot radius plus safety margin so the planned path is a valid **centre** trajectory.
- Unknown map cells are treated as blocked, so the planner never drives into unmapped space.
- Only the connected component reachable from the start pose is planned.
- Hairline gaps in walls are sealed morphologically so lanes cannot leak into another room.
- A Hough transform finds the dominant wall angle and the map is rotated so lanes run **parallel to the walls**.

---

## 🚦 Robot Navigation Pipeline

```mermaid
flowchart TD
    A["🗺️ Occupancy Grid Map<br/><i>saved from slam_toolbox</i>"] --> B["📡 SLAM / Scan Matching<br/><i>RPLIDAR C1</i>"]
    B --> C["📍 Localisation<br/><i>AMCL + EKF</i>"]
    C --> D["🧭 Coverage Planner<br/><i>bcd_coverage.py</i>"]
    D --> E["🛣️ Path Following<br/><i>Nav2 controller server</i>"]
    E --> F["⚙️ Motor Control<br/><i>STM32 over UART</i>"]
    F --> G["🧹 Cleaning Execution"]
    G -.->|"pose feedback"| C
```

---

## ⭐ Unique Closed-Loop Encoderless Control

> [!IMPORTANT]
> **The robot has no wheel encoders by design.** Closed-loop motion is recovered from two independent sources: verified step counts on the STM32, and integrated yaw rate from the MPU6050. This is one of the core engineering contributions of the project.

**Why no encoders**

- 💰 Removes two encoders, their wiring and their interrupt load.
- 🧪 Stepper motors already move in discrete, known increments, so position is commanded rather than measured.

**During straight motion**

- The STM32 is commanded an **exact pulse count** rather than a continuous velocity.
- The firmware counts every pulse it generates on the step timer.
- The next command is not accepted until the commanded step count has been **fully completed**.
- 📏 Distance therefore closes on the commanded value instead of on elapsed time.

**During turning**

- ❌ Wheel-derived heading is **not trusted**. A single lost step on an encoderless drivetrain corrupts the yaw estimate permanently.
- ✅ The MPU6050 gyroscope **z-axis rate is integrated** to obtain the angle actually turned.
- ✅ The measured angle is prioritised over the theoretical value predicted by wheel odometry.
- ✅ In the EKF, wheel odometry contributes translation only, and the gyro owns rotation entirely.

**Result**

| Behaviour | Before | After |
|---|---|---|
| Heading drift over repeated rotations | Accumulating | Substantially reduced |
| SLAM map doubling on turns | Present | Eliminated |
| Straight-line distance error | Time dependent | Step-count bounded |

---

## 🗺️ Mapping

**Pipeline**

- 📡 **RPLIDAR C1** publishes `/scan` at the robot base frame, orientation corrected in the URDF.
- 🧠 **slam_toolbox** runs in online asynchronous mode, building and optimising the pose graph.
- 🧱 The result is an **occupancy grid**: free, occupied and unknown cells at 5 cm resolution.
- 💾 The map is saved with `map_saver_cli` into a `.pgm` image plus a `.yaml` descriptor.
- 🧭 The saved map is then served to **AMCL** and to the coverage planner.

<div align="center">

<!-- 📸 Generated occupancy grid map -->
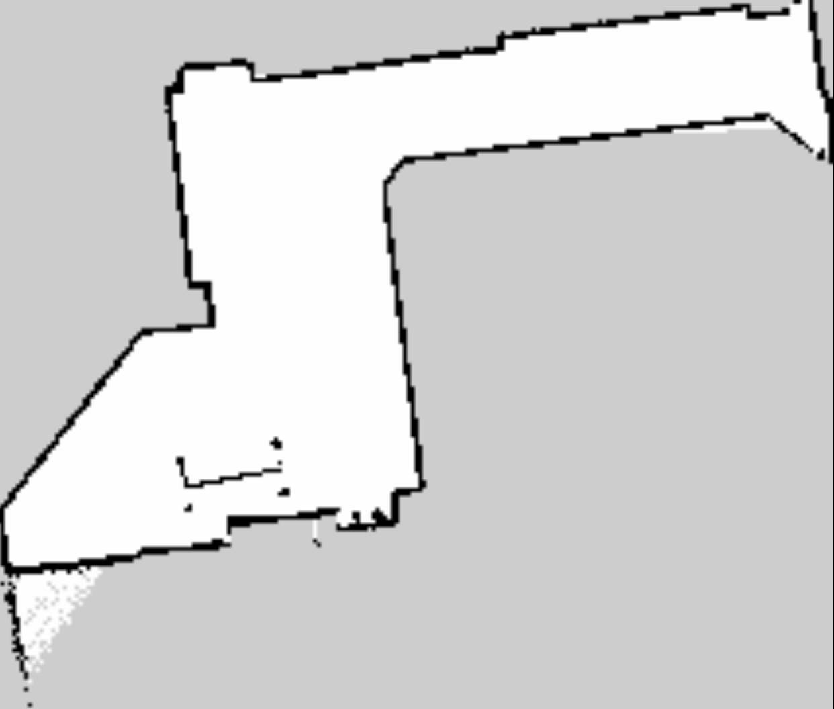
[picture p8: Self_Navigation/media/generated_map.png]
Generated occupancy grid map

<br><sub>Occupancy grid produced by slam_toolbox</sub>

<br><br>

<!-- 📸 Coverage path preview -->
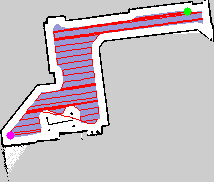
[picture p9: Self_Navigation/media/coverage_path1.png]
Boustrophedon coverage path planning

<br><sub>BCD coverage path generated over the saved map</sub>

<br><br>

<!-- 📸 Coverage path preview -->
Boustrophedon coverage path
<br><sub>BCD coverage path generated over the saved map</sub>

<br><br>

<!-- 📸 RViz2 visualisation -->
RViz2 navigation view
<br><sub>RViz2: map, costmaps, TF tree and colour-coded coverage waypoints</sub>

</div>

---

## 🎥 Navigation Demonstration

<div align="center">

<!-- 🎞️ Robot following the coverage path -->
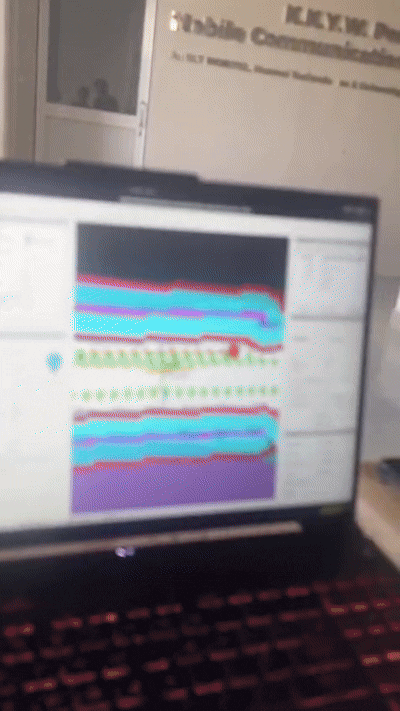
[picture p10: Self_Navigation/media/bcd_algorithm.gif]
Real robot navigation


<sub>Real robot navigation </sub>

<br><br>

Robot following the boustrophedon cellularcoverage path

<sub>Robot following the boustrophedon cellular decomposition coverage algorithm (on a different mapped area)</sub>

</div>

---

## 📂 Repository Structure

<details open>
<summary><b>🧭 Coverage planning</b></summary>

| File | Purpose | Importance | Stage |
|---|---|---|---|
| `bcd_coverage.py` | Standalone BCD planner. Sweep-line decomposition, Hough wall alignment, serpentine generation, YAML and preview export | 🔴 Core | Offline planning |
| `ros2_ws/src/minibot_coverage/minibot_coverage/prepare_map.py` | In-package map preparation and lane generation | 🔴 Core | Offline planning |
| `ros2_ws/src/minibot_coverage/minibot_coverage/coverage_server.py` | Replays the waypoint YAML through Nav2, tracks per-waypoint status, publishes `/coverage_waypoints` markers | 🔴 Core | Runtime |
| `ros2_ws/src/minibot_coverage/config/coverage_params.yaml` | Lane spacing, robot radius, tolerances | 🟠 High | Configuration |
| `ros2_ws/src/minibot_coverage/launch/coverage.launch.py` | Brings up the coverage server | 🟠 High | Launch |

</details>

<details>
<summary><b>🗺️ Navigation and SLAM</b></summary>

| File | Purpose | Importance | Stage |
|---|---|---|---|
| `ros2_ws/src/minibot_navigation/config/nav2_params.yaml` | Full Nav2 configuration: AMCL, planner, controller, costmaps, recoveries | 🔴 Core | Runtime |
| `ros2_ws/src/minibot_navigation/config/slam_mapping.yaml` | slam_toolbox online async parameters | 🔴 Core | Mapping |
| `ros2_ws/src/minibot_navigation/config/keepout_params.yaml` | Keep-out filter mask parameters | 🟡 Medium | Runtime |
| `ros2_ws/src/minibot_navigation/behavior_trees/navigate_through_poses_coverage.xml` | Behaviour tree tuned for long waypoint sequences | 🟠 High | Runtime |
| `ros2_ws/src/minibot_navigation/behavior_trees/navigate_to_pose_dock.xml` | Single-goal docking behaviour tree | 🟡 Medium | Runtime |
| `robot_files/slam_params.yaml` | Standalone SLAM parameter set used during bring-up | 🟡 Medium | Mapping |
| `robot_files/nav2_params.yaml` | Standalone Nav2 parameter set used during bring-up | 🟡 Medium | Runtime |

</details>

<details>
<summary><b>🤖 Robot description and visualisation</b></summary>

| File | Purpose | Importance | Stage |
|---|---|---|---|
| `ros2_ws/src/minibot_description/urdf/robot.urdf.xacro` | Top-level robot model | 🔴 Core | Bring-up |
| `ros2_ws/src/minibot_description/urdf/base.xacro` | Chassis, wheels, differential drive geometry | 🟠 High | Bring-up |
| `ros2_ws/src/minibot_description/urdf/lidar.xacro` | RPLIDAR C1 mount and frame, includes the 180° orientation fix | 🟠 High | Bring-up |
| `ros2_ws/src/minibot_description/urdf/imu.xacro` | MPU6050 frame definition | 🟠 High | Bring-up |
| `ros2_ws/src/minibot_description/urdf/ros2_control.xacro` | ros2_control hardware interface declaration | 🔴 Core | Bring-up |
| `ros2_ws/src/minibot_description/urdf/inertial_macros.xacro` | Reusable inertia macros | 🟡 Medium | Bring-up |
| `ros2_ws/src/minibot_description/rviz/navigation.rviz` | RViz2 layout for navigation and coverage | 🟠 High | Visualisation |
| `ros2_ws/src/minibot_description/rviz/view_robot.rviz` | RViz2 layout for model inspection | 🟡 Medium | Visualisation |
| `robot_files/robot.urdf` | Flattened URDF used during early bring-up | 🟡 Medium | Bring-up |

</details>

<details>
<summary><b>⚙️ Hardware interface and STM32 link</b></summary>

| File | Purpose | Importance | Stage |
|---|---|---|---|
| `ros2_ws/src/minibot_hardware/src/stepper_diffdrive.cpp` | `StepperDiffDrive` ros2_control system plugin, converts wheel commands to STM32 frames | 🔴 Core | Runtime |
| `ros2_ws/src/minibot_hardware/include/minibot_hardware/stepper_diffdrive.hpp` | Plugin interface declaration | 🟠 High | Runtime |
| `ros2_ws/src/minibot_hardware/include/minibot_hardware/serial_link.hpp` | UART transport, framing and timeout handling | 🔴 Core | Runtime |
| `ros2_ws/src/minibot_hardware/minibot_hardware.xml` | pluginlib export descriptor | 🟠 High | Build |
| `ros2_ws/src/minibot_hardware/test/test_protocol.cpp` | Unit tests for the serial protocol | 🟡 Medium | Verification |
| `robot_files/real_serial_bridge.py` | Lightweight Twist to UART bridge used before the ros2_control plugin | 🟡 Medium | Bring-up |

</details>

<details>
<summary><b>🔬 STM32 firmware</b></summary>

| File | Purpose | Importance | Stage |
|---|---|---|---|
| `stm32/Core/Src/minibot_motion.c` | Step generation, pulse counting and **step completion verification** | 🔴 Core | Real time |
| `stm32/Core/Inc/minibot_motion.h` | Motion module interface | 🟠 High | Real time |
| `stm32/Core/Src/minibot_protocol.c` | UART command parser and acknowledgement handling | 🔴 Core | Real time |
| `stm32/Core/Inc/minibot_protocol.h` | Protocol definitions shared with the Pi side | 🟠 High | Real time |
| `stm32/Core/Inc/minibot_config.h` | Steps per metre, wheelbase, microstepping, pin mapping | 🔴 Core | Configuration |
| `stm32/Core/Src/main.c` | Peripheral init and main control loop | 🟠 High | Real time |
| `stm32/Core/Src/tim.c` | Timer configuration driving the step pulses | 🟠 High | Real time |
| `stm32/Core/Src/usart.c` | UART peripheral configuration | 🟡 Medium | Real time |

</details>

<details>
<summary><b>🧭 IMU and sensor fusion</b></summary>

| File | Purpose | Importance | Stage |
|---|---|---|---|
| `ros2_ws/src/minibot_imu/minibot_imu/mpu6050_node.py` | Reads the MPU6050 over I2C, applies axis mapping, publishes `/imu/data` | 🔴 Core | Runtime |
| `ros2_ws/src/minibot_imu/minibot_imu/imu_calibrate.py` | Gyro bias calibration exposed as `/imu/recalibrate` | 🟠 High | Calibration |
| `ros2_ws/src/minibot_imu/config/imu_params.yaml` | Axis map, bias, covariance settings | 🟠 High | Configuration |
| `ros2_ws/src/minibot_imu/config/ekf.yaml` | robot_localization fusion matrix, wheel yaw deliberately disabled | 🔴 Core | Configuration |
| `ros2_ws/src/minibot_imu/launch/imu.launch.py` | IMU and EKF bring-up | 🟠 High | Launch |
| `robot_files/odometry_node.py` | Gyro-integrated odometry node with TF broadcast, used during bring-up | 🟠 High | Bring-up |
| `robot_files/imu_verify.py` | I2C level IMU verification utility | 🟡 Medium | Diagnostics |

</details>

<details>
<summary><b>🚀 Bring-up, launch and system integration</b></summary>

| File | Purpose | Importance | Stage |
|---|---|---|---|
| `ros2_ws/src/minibot_bringup/launch/robot.launch.py` | Full robot bring-up: description, controllers, LiDAR, IMU, EKF | 🔴 Core | Launch |
| `ros2_ws/src/minibot_bringup/launch/map.launch.py` | SLAM mapping session | 🔴 Core | Launch |
| `ros2_ws/src/minibot_bringup/launch/clean.launch.py` | Localisation, Nav2 and coverage in one cleaning run | 🔴 Core | Launch |
| `ros2_ws/src/minibot_bringup/launch/rviz.launch.py` | RViz2 with the navigation layout | 🟡 Medium | Launch |
| `ros2_ws/src/minibot_bringup/config/controllers.yaml` | `diff_drive_controller` and joint state broadcaster | 🔴 Core | Configuration |
| `ros2_ws/src/minibot_bringup/config/twist_mux.yaml` | Priority arbitration between teleop and Nav2 velocity commands | 🟠 High | Configuration |
| `ros2_ws/src/minibot_bringup/config/derived_params.yaml` | Steps per metre and geometry derived from `robot.yaml` | 🟠 High | Configuration |
| `ros2_ws/src/minibot_bringup/config/diagnostics.yaml` | Runtime diagnostics aggregation | 🟡 Medium | Configuration |
| `ros2_ws/src/minibot_bringup/scripts/calibrate_odom.py` | Empirical calibration of steps per metre and wheelbase | 🟠 High | Calibration |
| `ros2_ws/src/minibot_bringup/scripts/stm32_bench.py` | UART link latency and throughput benchmark | 🟡 Medium | Verification |
| `ros2_ws/src/minibot_bringup/udev/99-minibot.rules` | Stable device names for LiDAR and STM32 | 🟠 High | Deployment |
| `ros2_ws/src/minibot_bringup/systemd/minibot-robot.service` | Auto-start of the robot stack on boot | 🟡 Medium | Deployment |
| `ros2_ws/src/minibot_bringup/systemd/minibot-clean.service` | Auto-start of the cleaning run | 🟡 Medium | Deployment |
| `robot.yaml` | Single source of truth for all physical robot parameters | 🔴 Core | Configuration |

</details>

<details>
<summary><b>📖 Documentation</b></summary>

| File | Purpose |
|---|---|
| `docs/ARCHITECTURE.md` | System and node architecture |
| `docs/HARDWARE.md` | Wiring, power and component detail |
| `docs/INTERFACES.md` | UART protocol and ROS interface contracts |
| `docs/DERIVED_NUMBERS.md` | Derivation of steps per metre, wheelbase and limits |
| `docs/TESTING.md` | Test and verification procedure |
| `docs/FILE_MANIFEST.md` | Complete file inventory |

</details>

---

## 🔄 Complete System Workflow

```mermaid
flowchart TD
    U["👤 User<br/><i>starts cleaning run</i>"] --> M["🗺️ Saved Map<br/><i>.pgm + .yaml</i>"]
    M --> P["🧭 Coverage Planner<br/><i>Boustrophedon Cellular Decomposition</i>"]
    P --> R["🤖 ROS 2 Jazzy<br/><i>coverage_server.py</i>"]
    R --> N["🚦 Navigation2<br/><i>planner + controller server</i>"]
    N --> S["⚡ STM32F407<br/><i>UART command frames</i>"]
    S --> D["🔌 DRV8825 Drivers"]
    D --> MO["🔩 NEMA17 Stepper Motors"]
    MO --> RM["🧹 Robot Motion"]
    RM --> I["🧭 MPU6050 Feedback<br/><i>yaw rate</i>"]
    I --> H["🎯 Heading Correction<br/><i>gyro owns rotation</i>"]
    H --> S
    RM -.->|"/scan"| N
```

---

## ✨ Features

- ✅ Autonomous coverage path planning
- ✅ Boustrophedon Cellular Decomposition planner implemented from first principles
- ✅ Wall-aligned lane generation using Hough transform
- ✅ ROS 2 Jazzy and Navigation2 integration
- ✅ SLAM mapping with `slam_toolbox`
- ✅ AMCL localisation on the saved map
- ✅ RViz2 visualisation with live colour-coded coverage progress
- ✅ Closed-loop encoderless motion control
- ✅ MPU6050 yaw integration for rotation correction
- ✅ EKF sensor fusion with wheel yaw deliberately excluded
- ✅ Raspberry Pi 5 high-level planning
- ✅ STM32F407 real-time low-level control
- ✅ RPLIDAR C1 scanning and localisation
- ✅ Custom UART protocol with unit tests
- ✅ Systemd and udev deployment for headless operation

---

## 🚧 Future Improvements

| Area | Planned work |
|---|---|
| 🚧 Obstacle handling | Adaptive avoidance of dynamic obstacles during a sweep |
| 🔁 Replanning | Online re-decomposition when the map changes mid-run |
| 🏠 Multi-room | Room segmentation and inter-room sequencing |
| 🔋 Energy | Battery-aware planning with resume from the last waypoint |
| 📷 Vision | Camera integration for dirt and surface detection |
| 🧠 AI | Object detection to classify and avoid hazards |
| ☁️ Telemetry | Cloud monitoring of coverage reports |

---

<div align="center">

**Branch:** `Self_Navigation` &nbsp;•&nbsp; **Platform:** ROS 2 Jazzy on Raspberry Pi 5 &nbsp;•&nbsp; **Firmware:** STM32F407

</div>

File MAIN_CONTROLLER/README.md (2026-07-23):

# minibot_fw: Main Controller Firmware (STM32F407VET6)

Firmware for the main controller of the **Smart Autonomous Floor Mopping Robot**.
It runs on an STM32F407VET6 and owns four independent subsystems:

| Subsystem | Hardware | Control |
|---|---|---|
| **Drive** | 2 × stepper motor via DRV8825 | 40 kHz DDS pulse engine, jerk-limited S-curve profile, commanded over UART |
| **Mopping** | 4 × brushed DC motor via 2 × L298N | Fixed direction, on at boot, no speed control |
| **Water pump** | 1 × pump via IRLZ44N low-side MOSFET | Free-running timer: 3 s ON / 5 s OFF |
| **Host link** | USART1 → Raspberry Pi 5 | CRC-8 framed ASCII protocol, 50 Hz odometry feedback |

The drive layer is the only closed-loop-ish part: the Pi sends velocity targets, the
STM32 executes them and streams back an exact step count that serves as odometry.
The mop motors and pump are open-loop and run autonomously from power-on.

---

## ⚠️ Read this before you power the robot

**At power-on, with no host connected:**

| | State at boot |
|---|---|
| Stepper drivers | **Disabled** (PE3 nENABLE driven HIGH by `MX_GPIO_Init()` before anything else). Wheels do not move until a `$V` or `$E,1` command arrives. |
| 4 mop DC motors | **Running.** `main()` calls `DCM_Run()` unconditionally. They spin the moment the board is powered. |
| Water pump | **Cycling.** 5 s off, 3 s on, forever, from `Sig_Task()`. |

If you want a silent bench board, comment out `DCM_Run()` in `main()` and/or
`Sig_Init()`/`Sig_Task()`. Do this before the first power-up on a workbench; four
brushed motors starting unannounced is a good way to lose a finger or a probe.

**Common ground is mandatory.** STM32 GND, both L298N GND terminals, the MOSFET
source, and the 12 V battery negative must all be one node. Missing common ground
is the single most frequent cause of "the motors behave randomly".

---

## Hardware

| Item | Value |
|---|---|
| MCU | STM32F407VET6 (Cortex-M4F, 512 KB flash, 128 KB RAM) |
| Clock | HSE 8 MHz → PLL → **168 MHz** (see crystal warning below) |
| Toolchain | `arm-none-eabi-gcc` (13.2.1 verified) or STM32CubeIDE |
| Host link | USART1, 115200 8N1, no flow control |
| Drive | 2 × DRV8825, 1/16 microstep, 200 step/rev motors |
| Mop | 2 × L298N, 4 × brushed DC, 12 V |
| Pump | IRLZ44N low-side switch, 12 V |

### Complete pin map

| Pin | Function | Direction | Notes |
|---|---|---|---|
| **PE3** | `nENABLE`, both DRV8825 | out | **Active LOW.** HIGH = motors dead. Driven HIGH first thing at boot. |
| **PE4** | LEFT STEP | out | `GPIO_SPEED_FREQ_VERY_HIGH`, needed for clean 2 µs edges |
| **PE5** | LEFT DIR | out | |
| **PE6** | RIGHT STEP | out | |
| **PE7** | RIGHT DIR | out | |
| **PA9** | USART1_TX | out | → Raspberry Pi **RX** |
| **PA10** | USART1_RX | in | → Raspberry Pi **TX** |
| **PD0** | L298N #1 IN1 | out | Mop motor 1 |
| **PD1** | L298N #1 IN2 | out | Mop motor 1 |
| **PD2** | L298N #1 IN3 | out | Mop motor 2 |
| **PD3** | L298N #1 IN4 | out | Mop motor 2 |
| **PA2** | L298N #2 IN1 | out | Mop motor 3 |
| **PA3** | L298N #2 IN2 | out | Mop motor 3 |
| **PE14** | L298N #2 IN3 | out | Mop motor 4 |
| **PE15** | L298N #2 IN4 | out | Mop motor 4 |
| **PA12** | Pump gate (via 220 Ω) | out | USB_DM on this package, but USB is unused in this project |

TX/RX **cross over**: Pi TX → PA10, Pi RX → PA9, plus common GND.

Detailed wiring instructions, including diagrams, live in:

- [`WIRING_L298N.md`](WIRING_L298N.md): DC motor drivers, ENA/ENB tie-up, power distribution
- [`WIRING_PA12_PUMP.md`](WIRING_PA12_PUMP.md): MOSFET switch, flyback diode placement, gate pull-down

### ⚠️ Check your crystal before first flash

The firmware assumes an **8 MHz HSE crystal**. Many F407VET6 "black boards" ship
with **25 MHz**. If yours does and you don't change it, the baud rate *and* the
step rate are both wrong by the same 25/8 ratio: you get garbage on the serial
port and wrong motor speeds simultaneously, which is a confusing pair of symptoms
to debug.

Two edits:

| File | Change |
|---|---|
| `Core/Inc/stm32f4xx_hal_conf.h` | `#define HSE_VALUE ((uint32_t)25000000U)` |
| `Core/Src/main.c` → `SystemClock_Config()` | `osc.PLL.PLLM = 25;` |

Leave `PLLN`/`PLLP`/`PLLQ` alone. `PLLM` exists solely to bring the PLL input to
1 MHz (8/8 = 1, 25/25 = 1), so everything downstream still lands on 168 MHz.

### Clock tree

```
HSE 8 MHz ──/PLLM=8──► 1 MHz ──×PLLN=336──► 336 MHz ──/PLLP=2──► SYSCLK 168 MHz
                                                      /PLLQ=7──►  48 MHz (unused)

AHB  /1 → HCLK 168 MHz
APB1 /4 → PCLK1  42 MHz → TIM7 clock 84 MHz   (×2 rule when APB prescaler ≠ 1)
APB2 /2 → PCLK2  84 MHz → USART1
```

TIM7: `PSC = 84-1` (84 MHz → 1 MHz), `ARR = 25-1` (1 MHz → **40 kHz**).
Change the clock config and you *must* change these two numbers, or every step
rate (and therefore all odometry) is silently wrong by the same ratio.

---

## Drive architecture

Three layers, all inside the 40 kHz TIM7 ISR, plus a main-loop task.

```
TIM7 ISR @ 40 kHz ─┬─ Layer 1: DDS pulse engine
                   │    32-bit phase accumulator per motor.
                   │    inc = rate_hz × (2³² / 40000); acc += inc each tick;
                   │    a wrap past 2³² emits one STEP pulse AND bumps the
                   │    step counter in the same breath, which is why the
                   │    reported odometry is a tally, not an estimate.
                   │
                   └─ every 40th tick (1 kHz): Layer 2 + Layer 3
                        a += clamp(a_desired − a, ±jerk·dt)
                        v += a·dt                       ← S-curve, not trapezoid
                        v is SIGNED and passes through zero on a reversal, so
                        DIR only ever flips while the motor is ~stopped.

main loop ── MB_Task():  drain command queue, comms watchdog, 50 Hz feedback
          └─ Sig_Task():  non-blocking pump timer
```

**Why the DDS low-time is guaranteed, not lucky.** STEP is driven LOW at the top
of the ISR and HIGH at the bottom, giving ~23 µs high and ≥25 µs low against the
DRV8825's 1.9 µs minimum. If the accumulator increment is < 0.5 (i.e. step rate
< ISR_HZ/2 = 20 kHz), then immediately after a wrap the accumulator holds a value
below 0.5, so the *next* tick cannot wrap. Two pulses can never land on
consecutive ticks. At the configured ceiling of 1066 sps you are using **5.3 % of
that limit**, an enormous margin.

**Why jerk limiting matters here.** A plain trapezoidal ramp steps acceleration
discontinuously from 0 to a_max, which is a torque step, exactly the impulse
that makes a stepper skip. A coverage robot reverses at the end of every lane,
dozens of times per room, and there are no encoders to catch a skipped step. The
S-curve is what keeps the odometry honest across a full run.

### Interrupt priorities: do not reorder

| Interrupt | Preempt priority |
|---|---|
| TIM7 | **0** (highest) |
| USART1 | 1 |
| SysTick | 15 (lowest) |

The TIM7 ISR is ~2 µs. At 115200 baud a UART byte arrives every 87 µs, so even
worst case the UART is serviced ~2 µs late, 40× inside its deadline. Giving the
UART top priority "so we never miss a byte" trades a problem you don't have for
one you can't detect: a late step pulse is jitter at best and a lost step at
worst, and on an encoderless robot a lost step is a silent lie in the odometry.

---

## Serial protocol

ASCII, so you can drive it from a terminal.

```
$<PAYLOAD>*<CRC8><LF>
```

| Field | Meaning |
|---|---|
| `$` | Start of frame. Resynchronises the parser after any garbage. |
| `PAYLOAD` | Comma-separated fields; first field is the command letter. |
| `*` | End of payload. |
| `CRC8` | Two uppercase hex digits. **CRC-8/ATM**: poly `0x07`, init `0x00`, no reflection, no final XOR, computed over `PAYLOAD` only. |
| `LF` | `\n` |

### Pi → STM32

| Frame | Meaning |
|---|---|
| `$V,<left_sps>,<right_sps>*XX` | Signed steps/second target. Also implicitly enables the drivers and clears E-stop. |
| `$E,<0\|1>*XX` | Enable (1) / disable (0) the stepper drivers. |
| `$S*XX` | **Emergency stop.** Bypasses the ramp entirely and kills pulses immediately. |
| `$R*XX` | Reset step counters to zero. |
| `$P*XX` | Ping → STM32 replies `$K*F6`. |

### STM32 → Pi (50 Hz)

```
$F,<l_steps>,<r_steps>,<l_sps>,<r_sps>,<flags>,<seq>*XX
```

| Field | Type | Meaning |
|---|---|---|
| `l_steps`, `r_steps` | int32, signed, cumulative | **This is your odometry.** |
| `l_sps`, `r_sps` | int32 | Actual current step rate, post-profile |
| `flags` | bitfield | See below |
| `seq` | uint16, wraps | Lets the host detect dropped frames instead of silently interpolating across them |

| Flag | Value | Meaning |
|---|---|---|
| `MB_FLAG_ENABLED` | 1 | Drivers energised |
| `MB_FLAG_ESTOP` | 2 | Emergency stop latched |
| `MB_FLAG_CMD_TIMEOUT` | 4 | No command from host → ramped to stop |
| `MB_FLAG_CRC_ERR` | 8 | At least one bad CRC since boot (sticky) |
| `MB_FLAG_OVERRUN` | 16 | UART overrun seen since boot (sticky) |
| `MB_FLAG_CLAMPED` | 32 | Last command exceeded `MB_MAX_STEP_RATE` |

### Why CRC-8 and not a checksum

The motor wires running alongside this cable switch amps at kHz rates. One
flipped bit in a velocity command is a robot driving into a wall. CRC-8 catches
all single-bit errors, all double-bit errors, and all burst errors up to 8 bits.
A sum or XOR does not.

### Verified test vectors

Regenerated and confirmed against this source tree:

| Payload | CRC | Full frame |
|---|---|---|
| `V,1000,-1000` | `0x47` | `$V,1000,-1000*47\n` |
| `F,12345,-6789,500,-500,33,7` | `0x31` | *(feedback example)* |
| `P` | `0xB7` | `$P*B7\n` |
| `K` | `0xF6` | `$K*F6\n` (ping reply) |
| `S` | `0xBE` | `$S*BE\n` |
| `R` | `0xB9` | `$R*B9\n` |
| `E,1` | `0x83` | `$E,1*83\n` |
| `E,0` | `0x84` | `$E,0*84\n` |

Copy-paste bench test from a Linux host:

```bash
stty -F /dev/ttyUSB0 115200 raw -echo
cat /dev/ttyUSB0 &                          # watch $F frames at ~50 Hz
printf '$P*B7\n'          > /dev/ttyUSB0    # expect $K*F6 back
printf '$V,500,500*XX\n'  > /dev/ttyUSB0    # replace XX with the real CRC
printf '$S*BE\n'          > /dev/ttyUSB0    # emergency stop
```

Reference CRC helper:

```python
def crc8(payload: str) -> str:
    c = 0
    for ch in payload.encode():
        c ^= ch
        for _ in range(8):
            c = ((c << 1) ^ 0x07) & 0xFF if c & 0x80 else (c << 1) & 0xFF
    return f"{c:02X}"

def frame(payload: str) -> bytes:
    return f"${payload}*{crc8(payload)}\n".encode()
```

---

## Configuration

All drive tuning lives in [`Core/Inc/minibot_config.h`](Core/Inc/minibot_config.h).

| Constant | Value | Meaning |
|---|---|---|
| `MB_STEPS_PER_REV` | 3200 | 200 steps/rev × 16 microstep |
| `MB_WHEEL_RADIUS_M` | 0.0336 | 67.2 mm wheel diameter |
| `MB_WHEEL_SEP_M` | 0.400 | Track width |
| `MB_MAX_STEP_RATE` | 1066 sps | ≈ 20 RPM |
| `MB_MIN_STEP_RATE` | 266 sps | ≈ 5 RPM |
| `MB_MAX_ACCEL_SPS2` | 2132 | 0 → max in 0.5 s |
| `MB_MAX_JERK_SPS3` | 14213.3 | 0 → max accel in 0.15 s |
| `MB_ISR_HZ` | 40000 | TIM7 step-engine tick |
| `MB_RAMP_HZ` | 1000 | Profile update rate |
| `MB_FEEDBACK_HZ` | 50 | `$F` frame rate |
| `MB_CMD_TIMEOUT_MS` | 500 | Comms watchdog |
| `MB_IDLE_DISABLE_MS` | 10000 | Drop coils after idle |
| `MB_LEFT_DIR_INVERT` | 1 | Per-side direction flip |
| `MB_RIGHT_DIR_INVERT` | 0 | |

### Derived motion envelope

| Quantity | Value |
|---|---|
| Wheel circumference | 211.1 mm |
| Distance per step | **65.97 µm** |
| Max linear speed | ≈ **70 mm/s** |
| Min linear speed | ≈ 17.5 mm/s |
| Max yaw rate (spin in place) | ≈ 0.35 rad/s (20 °/s) |

### Fixing direction problems

| Symptom | Fix |
|---|---|
| Robot **spins** instead of driving forward | Flip exactly **one** of `MB_LEFT_DIR_INVERT` / `MB_RIGHT_DIR_INVERT` |
| Robot drives **backwards** | Flip **both** |
| A mop motor turns the wrong way | Swap its two `OUTx` wires, or swap `DCM_CW`/`DCM_CCW` for that motor in `DCM_Run()` |

### Pump timing

Edit `Core/Src/minibot_signal.c`:

```c
#define SIG_HIGH_MS   3000u   /* pump ON  time (ms) */
#define SIG_LOW_MS    5000u   /* pump OFF time (ms) */
```

The pump starts in the OFF phase at boot, which is the safe default.

---

## Build and flash

### Option A: Makefile (no IDE required)

```bash
sudo apt install gcc-arm-none-eabi stlink-tools

make          # → build/minibot.elf, .hex, .bin
make flash    # ST-Link
make dfu      # USB DFU: hold BOOT0, tap RESET, then run this
make size
make clean
```

The Makefile compiles a fixed source list and builds at `-O2`.

### Option B: STM32CubeIDE

1. **File → Switch Workspace → Other…** Pick a folder that is **not** this
   project directory. Opening the project folder as the workspace is what causes
   the *"already exist in the workspace"* import error.
2. **File → Import → General → Existing Projects into Workspace**
3. Root directory: this folder. `minibot_fw` appears checked → **Finish**
4. `Ctrl+B` to build, then flash `Debug/minibot_fw.elf`.

CubeIDE's managed build auto-discovers every `.c` under `Drivers/`, unlike the
Makefile's fixed list, so keep `Drivers/` free of unused vendor subtrees (the
CMSIS `DAP/`, `Core/`, `Core_A/` folders and HAL `Src/Legacy/` were removed for
exactly this reason).

If CubeIDE keeps fighting you, use **File → Import → C/C++ → Existing Code as
Makefile Project**, toolchain *Cross ARM GCC*. You get the editor and debugger;
`make` does the building.

### Option C: CubeMX regeneration

`minibot_fw.ioc` matches the peripheral setup in `main.c`. Regenerating
**overwrites** `main.c`, `gpio.c`, `tim.c`, `usart.c`. Everything project-specific
lives either between `USER CODE BEGIN/END` markers or in `minibot_*.c/h`, which
CubeMX never touches. Diff before you commit.

### Build size

Measured from the committed `Debug/minibot_fw.elf` (CubeIDE debug build, `-O0 -g`):

```
FLASH:  42,052 B / 524,288 B   ( 8.0 % )
RAM  :   3,776 B / 131,072 B   ( 2.9 % )
```

The `-O2` Makefile build is roughly half the flash. Either way there is a great
deal of headroom.

---

## Repository layout

```
minibot_fw/
├── Core/
│   ├── Inc/
│   │   ├── main.h                 ← complete pin map lives here
│   │   ├── minibot_config.h       ← all drive tuning constants
│   │   ├── minibot_motion.h       ← step-engine design rationale
│   │   ├── minibot_protocol.h     ← wire format spec
│   │   ├── minibot_dcmotor.h      ← L298N mop-motor module
│   │   ├── minibot_signal.h       ← PA12 pump timer
│   │   ├── gpio.h  tim.h  usart.h  stm32f4xx_hal_conf.h  stm32f4xx_it.h
│   ├── Src/
│   │   ├── main.c                 ← boot order, clock config, HAL callbacks
│   │   ├── minibot_motion.c       ← DDS + S-curve + watchdog + feedback (379 lines)
│   │   ├── minibot_protocol.c     ← CRC-8, frame parser, frame builder
│   │   ├── minibot_dcmotor.c      ← 4 DC motors, 8 IN pins
│   │   ├── minibot_signal.c       ← pump 3 s / 5 s cycle
│   │   ├── gpio.c  tim.c  usart.c  stm32f4xx_hal_msp.c  stm32f4xx_it.c
│   │   └── syscalls.c  sysmem.c  system_stm32f4xx.c
│   └── Startup/startup_stm32f407xx.s
├── Drivers/                       ← ST HAL + CMSIS (vendor code, unmodified)
├── Debug/                         ← CubeIDE build output (see note below)
├── prebuilt/REBUILD_REQUIRED.txt  ← old binaries deliberately removed
├── Makefile                       ← standalone GCC build
├── STM32F407VETX_FLASH.ld
├── minibot_fw.ioc                 ← CubeMX project
├── minibot_fw.launch              ← ST-Link debug config
├── WIRING_L298N.md
└── WIRING_PA12_PUMP.md
```

**Your code is in `minibot_motion.c`, `minibot_protocol.c`, `minibot_dcmotor.c`,
`minibot_signal.c` and `minibot_config.h`.** Everything else is CubeMX-generated
or ST vendor code.

---

## Bring-up checklist

Work through this in order the first time. Robot on blocks, wheels off the ground.

1. **Crystal.** Confirm 8 MHz vs 25 MHz and patch if needed (see above).
2. **Grounds.** STM32 GND, both L298N GND, MOSFET source, battery −. All one node.
3. **Power the board with motor power OFF.** Confirm the stepper drivers stay
   disabled and nothing moves.
4. **Serial link.** `$P*B7` → expect `$K*F6`. Confirm `$F` frames arrive at
   ~50 Hz with `flags` = 0 or 4 (`CMD_TIMEOUT` is expected before you send
   anything).
5. **Microstepping sanity.** Command exactly one wheel revolution: `$V` at a
   known rate for a known duration, or reset counters with `$R` and watch
   `l_steps` reach 3200. Mark the wheel and the floor. **If the DRV8825 jumpers
   are actually 1/8, or the motors are 0.9°/step, every distance is silently 2×
   wrong and nothing in the system will tell you.**
6. **Direction.** Command forward. Fix with the `*_DIR_INVERT` flags, not by
   swapping wires, so the config stays the source of truth.
7. **Watchdog.** Stop sending commands mid-motion. The robot should ramp to a
   stop within ~500 ms and set flag bit 4, while staying energised.
8. **E-stop.** Send `$S*BE` at speed. Motion must cease immediately.
9. **Mop motors and pump** last, with the drivetrain verified.

---

## Safety behaviour

| Mechanism | Behaviour |
|---|---|
| **Boot order** | `MX_GPIO_Init()` runs before any other peripheral and drives nENABLE HIGH, so the steppers are dead before anything can twitch. `DCM_Init()` pre-loads all L298N IN pins LOW *before* switching them to outputs, so no mop motor twitches during bring-up. |
| **Comms watchdog** | No command for 500 ms → ramp to stop, but **stay energised**, keeping holding torque so the robot doesn't roll on a slope. |
| **Idle disable** | No command for 10 s → drop the coils. A stationary stepper at full current is a ~10 W heater doing no work. |
| **Emergency stop** | Bypasses the profile entirely. Losing steps is an acceptable trade for stopping now. |
| **Fault handlers** | HardFault / BusFault / UsageFault kill the steppers **and** call `DCM_StopAll()`, then hang. Firmware that has faulted must not still be driving motors. |
| **NaN guard** | Non-finite velocity → stop. |
| **UART overrun recovery** | An unhandled ORE silently kills RX forever, so `MB_UartErrorISR()` clears every error flag and re-arms reception. |
| **CRC rejection** | Frames with a bad CRC are discarded silently and flagged, never acted on. |

---

## Troubleshooting

| Symptom | Likely cause |
|---|---|
| Garbage on serial **and** wrong motor speeds | 25 MHz crystal, unpatched. Both scale by 25/8. |
| Motors hum but don't turn | Driver current limit too low, or STEP edges too slow down long jumper wires |
| Motor "sometimes just doesn't move" | STEP line slew rate; keep `GPIO_SPEED_FREQ_VERY_HIGH`, shorten the wire |
| Robot spins instead of driving forward | Flip exactly one `*_DIR_INVERT` |
| Distances consistently 2× off | DRV8825 microstep jumpers don't match `MB_STEPS_PER_REV` |
| Flag bit 4 (`CMD_TIMEOUT`) always set | Host isn't sending, or CRC mismatch; check flag bit 8 |
| Flag bit 8 (`CRC_ERR`) sticky | Wiring noise, wrong baud, or a host-side CRC implementation bug |
| Flag bit 16 (`OVERRUN`) sticky | Host is flooding the link, or an ISR is running long |
| Mop motors do nothing | ENA/ENB jumpers missing → enable node not at +5 V |
| Mop motors behave randomly | No common ground |
| Pump twitches at power-up | Missing 10 kΩ gate pull-down; PA12 is high-Z during reset |
| MOSFET runs hot | 3.3 V gate drive raises R_DS(on); add a heatsink or a gate driver |

---

## Known gaps and open items

Documented honestly so the next person doesn't lose an evening:

- **`minibot_config.h` claims to be auto-generated** from `robot.yaml` by
  `tools/generate_config.py`. Neither file is in this tree. Until they are
  restored, the header **is** the source of truth and must be hand-edited, and the
  "do not hand-edit" banner is currently misleading.
- **`stm32_bench.py` is referenced but absent.** Step-verification has to be done
  manually (see the bring-up checklist) or with your own host script.
- **`prebuilt/` contains no binaries.** They were removed deliberately: they
  predate the L298N module and would run the robot with the mop motors dead.
  Build from source.
- **Comment/code mismatch in `main.c`.** Two comments describe the PA12 pump as
  "4 s HIGH / 4 s LOW"; the implementation in `minibot_signal.c` is 3 s / 5 s.
  The code is correct, the comments are stale.
- **`Debug/` build artifacts are committed** (~30 MB of `.o`, `.elf`, `.map`,
  `.list`). Consider adding a `.gitignore` and untracking them:

  ```gitignore
  Debug/
  build/
  *.o
  *.elf
  *.bin
  *.hex
  *.list
  *.map
  *.su
  *.cyclo
  *.d
  ```

  ```bash
  git rm -r --cached MAIN_CONTROLLER/firmware_Main/minibot_fw/Debug
  ```

- **No PWM speed control for the mop motors.** All eight free pins are used as
  L298N IN lines, so ENA/ENB are hard-tied to +5 V. Adding speed control needs two
  more free pins fed from a timer PWM output.
- **No encoders.** Odometry is an exact tally of emitted step pulses, which is
  correct only as long as no step is skipped. That's why the jerk limiting and the
  DIR-through-zero rule matter, and why step verification is on the checklist.
- **The mop motors and pump run open-loop from boot** with no host command and no
  way to stop them over the serial link. If host-controlled mopping is wanted,
  `DCM_Set()` and the pump need protocol commands wired to them.

---

## License

The `Drivers/` tree contains ST and ARM vendor code under their respective
licenses (see `Drivers/CMSIS/LICENSE.txt`,
`Drivers/STM32F4xx_HAL_Driver/LICENSE.md`). Project code in `Core/` is part of the
Smart Autonomous Floor Mopping Robot project.

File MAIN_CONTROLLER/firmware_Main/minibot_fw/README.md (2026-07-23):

# iMX6 Rex — 12-Layer PCB Design

PCB Front

> A custom 12-layer PCB design for the **Wandboard iMX6 Rex** System-on-Module (SoM), built upon the open-source schematic and fully routed by hand.

---

## 📌 Overview

This project is a complete PCB layout for the **i.MX6 Rex** SoM — a compact, high-performance embedded computing module based on the **NXP i.MX6** application processor. The schematic was sourced from the open-source Wandboard/iMX6 Rex reference design, and the **PCB layout was designed entirely from scratch** by me using professional EDA tooling.

The board features a dense 12-layer stackup to accommodate DDR memory routing, high-speed differential pairs, power planes, and controlled-impedance traces — all within a compact SoM form factor.

---

## 🖼️ PCB Images

### 3D Render — Front
PCB Front Render

### 3D Render — Back
PCB Back Render

### Layer Stackup Views

| Layer | Preview |
|---|---|
| L1 — Top Copper | L1 |
| L2 | L2 |
| L3 | L3 |
| L4 | L4 |
| L5 | L5 |
| L6 | L6 |
| L7 | L7 |
| L8 | L8 |
| L9 | L9 |
| L10 | L10 |
| L11 | L11 |
| L12 — Bottom Copper | L12 |

---

## 🧠 Processor & Key Components

| Component | Details |
|---|---|
| **SoC** | NXP i.MX6 (Solo / Dual / Quad) |
| **RAM Interface** | DDR3 / DDR3L |
| **Form Factor** | SoM (System-on-Module) |
| **Connectors** | High-density board-to-board (J1, J2) |
| **Power** | Multi-rail PMIC with 1V375, 1V5, 2V5, 3V3 rails |
| **Crystal** | CPU XTALI / XTALO oscillator circuit |
| **Ethernet PHY** | On-board (ETH) |

---

## 📐 PCB Specifications

| Parameter | Value |
|---|---|
| **Layers** | 12 |
| **Board Dimensions** | ~67.6 × 37.6 mm (SoM standard) |
| **Min Trace Width** | Controlled impedance differential pairs |
| **Mounting Holes** | 4× GND-connected mounting points |
| **Surface Finish** | ENIG (recommended) |
| **Stackup** | Signal / GND / Signal / Power / GND / Signal / Signal / GND / Power / Signal / GND / Signal |

---

## 🔧 Layer Description

| Layer | Function |
|---|---|
| L1 | Top signal — component placement, fine routing |
| L2 | Ground plane |
| L3 | Signal — DDR and high-speed routing |
| L4 | Power plane (VDD_DDR, 1V375, etc.) |
| L5 | Signal |
| L6 | Ground plane |
| L7 | Ground plane |
| L8 | Signal |
| L9 | Power plane (3V3, 1V5, 2V5) |
| L10 | Signal — DDR and high-speed routing |
| L11 | Ground plane |
| L12 | Bottom signal — passive components |

---

## 🛠️ Design Process

1. **Schematic** — Based on the open-source iMX6 Rex reference schematic (Wandboard project)
2. **Netlist Import** — Imported into EDA tool and components placed manually
3. **Component Placement** — SoC centered, DDR ICs flanking, power circuitry on periphery
4. **Layer Stackup Definition** — 12-layer impedance-controlled stackup defined
5. **Critical Routing** — DDR3 length-matched, differential pairs (USB, Ethernet, LVDS) impedance-controlled
6. **Power Planes** — Copper pours defined per rail with proper decoupling
7. **Via Strategy** — Blind/buried via patterns used around BGA to escape signals
8. **DRC & Review** — Design rule checks passed; stackup and impedance verified

---

## 📁 Repository Structure

```
iMX6-Rex-PCB/
├── README.md
├── iMX6_Rex_V1I1_PCB.png       # 3D render — front
├── iMX6_Rex_V1I1_PCB_B.png     # 3D render — back
├── L_1.png                      # Layer 1 (Top)
├── L_2.png                      # Layer 2
├── L_3.png                      # Layer 3
├── L_4.png                      # Layer 4
├── L_5.png                      # Layer 5
├── L_6.png                      # Layer 6
├── L_7.png                      # Layer 7
├── L_8.png                      # Layer 8
├── L_9.png                      # Layer 9
├── L_10.png                     # Layer 10
├── L_11.png                     # Layer 11
└── L_12.png                     # Layer 12 (Bottom)
```

---

## 📜 Credits & Open Source Acknowledgement

- **Reference Schematic:** [Wandboard iMX6 Rex](https://www.wandboard.org/) — open-source hardware project
- **PCB Layout:** Designed from scratch by **[Your Name]**
- The schematic was used as a reference only; all component placement, routing, layer stackup, and design decisions were made independently

---

## 📄 License

The original schematic is released under open-source hardware terms by the Wandboard project. The PCB layout files in this repository are the original work of the author.

---

## 🤝 Contact

If you have questions about the design or want to collaborate, feel free to open an issue or reach out via GitHub.

---

*Designed with passion for embedded hardware engineering.* 🔌

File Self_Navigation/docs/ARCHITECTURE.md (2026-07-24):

# Architecture

## The three phases

```
PHASE 1 — MAP (once)                          PHASE 2 — PLAN (offline, laptop)
────────────────────                          ────────────────────────────────
robot.launch.py                               prepare_map.py
  + map.launch.py  (slam_toolbox)               ├─ clean:  seal wall gaps, despeckle
  + teleop                                      ├─ QA:     reachability, bottlenecks, time
        │                                       ├─ plan:   edge pass + 19 cm boustrophedon
        ▼                                       └─ render: a PNG you LOOK AT
  map_saver_cli                                       │
        │                                             ▼
        └──────► home.pgm / home.yaml ──────►  home_coverage_path.yaml
                                                home_qa.txt
                                                home_coverage_preview.png

PHASE 3 — CLEAN (every run, all on the Pi)
──────────────────────────────────────────
  map_server ──► AMCL ──────────────────────► map → odom  (corrections; JUMPS)
                   ▲
                  /scan
                   │
  coverage_server ─┴─► NavigateThroughPoses ─► bt_navigator
        (plays back the frozen path)                │
                                                    ▼
                                    planner_server (NavFn)
                                    controller_server (RegulatedPurePursuit)
                                                    │
                                          /cmd_vel_smoothed
                                                    │
                                       twist_stamper ──► /nav_vel
                                                    │
                                       twist_mux ───┴── /joy_vel (priority 100)
                                                    │
                                   /diff_drive_controller/cmd_vel
                                                    │
                                        diff_drive_controller
                                                    │
                            minibot_hardware/StepperDiffDrive
                                                    │
                                 $V,<l>,<r>*CRC over UART @ 115200
                                                    │
                                              STM32F407
                                                    │
                                   40 kHz DDS + S-curve profile
                                                    │
                                         2× DRV8825 → 2× NEMA-17

  STM32 ──► $F,<steps>,... @ 50 Hz ──► StepperDiffDrive
                                             │
                            /diff_drive_controller/odom  (enable_odom_tf: FALSE)
                                             │
  MPU6050 ──► /imu/data_raw ──► madgwick ──► /imu/data  (publish_tf: FALSE)
                                             │
                                        ekf_filter_node
                                             │
                            /odom  AND  odom → base_link  ◄── SOLE PUBLISHER
```

## TF tree

```
map                     ← AMCL (phase 3) or slam_toolbox (phase 1)
 └── odom               ← robot_localization EKF.  ONLY THIS NODE.
      └── base_link     ← the centre of rotation = the centre of the disc
           ├── base_footprint
           ├── body
           ├── left_wheel      (continuous, from joint_state_broadcaster)
           ├── right_wheel     (continuous)
           ├── caster_front / caster_rear
           ├── lidar_frame     ← CENTRED at x=0, y=0
           └── imu_link
```

### The single most common way to break this robot

**Two publishers on `odom → base_link`.** The symptom is the robot flickering
between two poses in RViz and the local costmap jittering. Guard it with:

```
diff_drive_controller : enable_odom_tf = false
imu_filter_madgwick   : publish_tf     = false
ekf_filter_node       : publish_tf     = true      ← the only one
```

### Why `world_frame: odom` and not `map` in the EKF

`odom → base_link` must be **smooth and continuous** — Nav2's local costmap
depends on it. AMCL's corrections are **discontinuous**: it jumps. Those jumps
belong on the `map → odom` edge, where nothing downstream integrates them. Set
`world_frame: map` and you get AMCL's jumps injected into the local costmap.

---

## Where odometry comes from with no encoders

The STM32 **generates** every STEP pulse, so it knows exactly how many it emitted
and in which direction. It reports that tally at 50 Hz:

```
position_rad = steps × 2π / steps_per_rev
```

This is **not an estimate**. It is a count of pulses that physically left the pin.
It is exact right up until the motor *skips a step*.

That is the whole design constraint, and it drives three decisions:

1. **The 20 RPM cap and the jerk-limited S-curve** exist to make skipping
   arbitrarily unlikely. At 1066 sps you're at 5.3 % of the pulse engine's
   ceiling and nowhere near the motor's torque limit.
2. **The MPU6050 is fused in** to catch the *heading* error that a skipped step
   would otherwise hide. The gyro measures yaw **rate** directly — it doesn't
   care about wheel slip, wheel radius, or wheel separation.
3. **AMCL, not slam_toolbox localization.** slam_toolbox's own README says its
   localization mode *"needs high quality odometry"*. Open-loop step counts are,
   by definition, not that. AMCL's motion model has explicit noise parameters
   (`alpha1..alpha5`) where you **tell it** how bad your odometry is:

   ```yaml
   alpha1: 0.30   # rotation noise from rotation       ← HIGH: the weak axis
   alpha3: 0.05   # translation noise from translation ← LOW: steps are exact
   ```

   Note that translation really *is* exact here: at 33.6 mm wheels each step is
   **0.066 mm** of travel — a very fine ruler. Rotation is the weak axis because
   it divides by `wheel_separation`, which you measured with a tape.

   That asymmetry *is* the encoding of "no encoders". A scan matcher has no such
   release valve.

---

## Why a circular robot makes coverage tractable

For a disc, **inscribed radius == circumscribed radius**. For *this* robot that radius is **0.210 m** — half the **wheel** span, because the wheels (410–420 mm) are wider than the body (380 mm). The robot can
rotate in place *anywhere it can physically stand*. A rectangular robot cannot —
it needs extra clearance to sweep its corners around.

Consequence: **every point on the coverage path is automatically a valid turning
point.** That's why Nav2 gets `robot_radius: 0.19` (a scalar) instead of a
footprint polygon, and why the boustrophedon lanes can be planned without any
turn-feasibility check.

---

## The velocity chain — every layer must agree

```
Nav2 FollowPath  ≤  velocity_smoother  ≤  diff_drive_controller
    ≤  Pi-side clamp (max_step_rate)  ≤  STM32 clamp (MB_MAX_STEP_RATE)
    ≤  what the motor can do without skipping
```

If any layer asks for more than the one below it can deliver, the excess is
**silently clipped** — and then the planner believes the robot went somewhere it
did not. This single class of bug causes more "my odometry is drifting" reports
than anything else.

**That is why `tools/generate_config.py` exists.** The same physical constants
are needed in five places. Generate them; never hand-maintain five copies.

```bash
python3 tools/generate_config.py          # writes them
python3 tools/generate_config.py --check  # exits 1 if stale — wire into CI
```

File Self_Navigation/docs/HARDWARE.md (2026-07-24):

# Hardware — the definitive record

**Everything in this project derives from this page. If a number here is wrong,
everything downstream is wrong.** Revision 1 proved that the hard way.

## Confirmed by measurement

| | Value | Notes |
|---|---|---|
| **Wheel diameter** | **67.2 mm** (with rubber) | → radius **0.0336 m**. *Measure it LOADED* — rubber compresses ~1 mm, and 1 mm on a 33.6 mm radius is a **3 % odometry error**. |
| **Wheel separation** | **0.400 m** | Centre-to-centre of the contact patches. (Outer ends are 41–42 cm; the kinematics needs the **midpoint** figure.) |
| **Wheel outer span** | **0.410–0.420 m** | → **`robot_radius` = 0.210 m** |
| **Body diameter** | 0.380 m | Chassis disc. **Narrower than the wheels.** |
| **LIDAR height** | **0.250 m** from the ground | → URDF `lidar_z` = 0.250 − 0.0336 = **0.2164 m** |
| **Cleaning brushes** | 2 × 100 mm dia, centres 200 mm apart | → **swept width 0.300 m**, **100 mm gap in the middle** |
| **Robot mass** | ~6 kg | |
| Main controller | STM32F407VET6 | |
| Compute | Raspberry Pi 5 | ROS 2 Jazzy |
| Motor drivers | 2 × DRV8825 @ **1.4 A** | Microstep jumpers **M0=LOW, M1=LOW, M2=HIGH** (1/16) |
| Motors | 2 × NEMA-17 42-34 | **NO ENCODERS.** Open loop. |
| LIDAR | RPLIDAR C1 | USB |
| IMU | MPU6050 | I²C-1, addr 0x68 |

## :rotating_light: THE WHEELS ARE THE WIDEST PART OF THE ROBOT

```
        body: 380 mm  ├────────────────────┤
      wheels: 420 mm ├──────────────────────┤   ← WIDER
```

Nav2 gets **`robot_radius: 0.210`** — half the *wheel* span, not half the body.

Plan against 0.190 and Nav2 will confidently drive the **wheels** into walls it
believes the *body* clears. This is the kind of error that presents as
"the robot keeps scraping along walls" and looks like a controller problem.

## :rotating_light: The 9 cm wall strip — a MECHANICAL limit

```
wall │
     │←── 0.240 m ──→│              robot centre can get no closer
     │               ●              (robot_radius 0.210 + safety 0.030)
     │←9cm→│←──── 0.300 m brush ────→│
     │▓▓▓▓▓│                          the brush stops 9 cm short
     └ NEVER CLEANED
```

**No software fixes this.** Your options:
1. **Accept** a 9 cm uncleaned perimeter
2. Drop `safety_margin` 0.03 → 0.01 → strip becomes **7 cm** (costs wall clearance)
3. **Mount the brushes further outboard** — the real fix

## :warning: The 100 mm gap between your brushes — CONFIRM THIS

```
   left brush          GAP           right brush
  ├─────────┤    ├───────────┤    ├─────────┤
 -0.15    -0.05  -0.05    +0.05  +0.05    +0.15
```

This is **normal and fine IF your suction inlet sits in that gap** (side brushes
sweeping debris inward to a central intake is the standard robot-vacuum design).

**If there is nothing in the middle, you have a 100 mm uncleaned stripe down the
centre of every single lane**, and no path planner can fix it. The coverage
"% swept" readout would then be *overstating* reality.

## :rotating_light: The 20 RPM cap is costing you an hour per run

| RPM | Speed | Step rate | Pulse engine used | 49 m² flat |
|---|---|---|---|---|
| **20** *(your spec)* | 0.070 m/s | 1066 sps | **5.3 %** | **94 min** |
| 40 | 0.141 m/s | 2133 sps | 10.7 % | 47 min |
| 60 | 0.211 m/s | 3200 sps | 16.0 % | **31 min** |
| 100 | 0.352 m/s | 5333 sps | 26.7 % | 19 min |

At 20 RPM the pulse engine is **5 % used** and the motors have **~12× torque
margin** at 6 kg. **The cap is buying you nothing.**

Add the lane-spacing fix (0.19 → 0.25, still 5 cm of overlap on a 0.30 m brush)
and 60 RPM gives you **26 minutes for identical coverage**.

Both are **one line each** in `robot.yaml`. I left them at your stated values.

## GPIO UART wiring — Pi 5 <-> STM32 (no USB adapter)

The STM32 <-> Pi link is a direct 3-wire UART connection, not USB:

```
   Pi 5 GPIO header              STM32F407VET6
   GPIO15 / pin 10 (RXD) <------- PA9  (USART1_TX)
   GPIO14 / pin 8  (TXD) -------> PA10 (USART1_RX)
   GND     / pin 6, 9...  ------- GND
```

TX crosses to RX and RX crosses to TX — wiring TX-to-TX gives silence on
both ends. Common ground is not optional; without it the UART has no shared
voltage reference. Both sides are native 3.3V logic, so no level shifter.

**Pi 5-specific step — this is the part every Pi 4 tutorial gets wrong for
you.** Add to `/boot/firmware/config.txt`:

```
dtoverlay=uart0-pi5
```

Reboot, then it appears as `/dev/ttyAMA0`. Unlike a Pi 4, the Pi 5's console
lives on its dedicated 3-pin debug UART connector, not on GPIO14/15 — so
there is normally no serial-console-login-shell conflict to disable first.

Verify before trusting anything above this layer:

```bash
ros2 run minibot_bringup stm32_bench.py --watch
#   -> "$F,..." feedback frames at ~50 Hz
```

If nothing appears, check in order: TX/RX crossover, common ground, the
`dtoverlay=uart0-pi5` line (and that you rebooted after adding it), then
baud rate (115200) and the HSE crystal (see risk #6 below) — a mismatched
crystal desyncs both the baud rate *and* the step rate simultaneously,
which is a confusing pair of symptoms to debug separately.

**Tradeoff vs. a USB-TTL adapter:** GPIO UART is simpler (2 signal wires,
no extra chip) but shares the Pi's ground plane directly with the STM32
board. Keep that board's ground solidly tied and route these three wires
away from the DRV8825/motor wiring to avoid noise coupling.

## Still UNVERIFIED — these are the remaining risks

| # | Unknown | Why it matters | How to resolve |
|---|---|---|---|
| 1 | **Motor holding torque at 1.4 A** | I assumed 0.40 N·m (typical for the size class). All torque margins depend on it. | Read the label / datasheet on your actual motor |
| 2 | **1.8°/step or 0.9°/step?** | A 2× error in every distance | `stm32_bench.py --verify-steps` |
| 3 | **Microstep jumpers really 1/16?** | A 2× error in every distance | Same test |
| 4 | **Suction inlet in the brush gap?** | 100 mm stripe down every lane if not | Look at the robot |
| 5 | **IMU height** | I guessed 60 mm | Measure it |
| 6 | **HSE crystal — 8 MHz or 25 MHz?** | Wrong baud **and** wrong step rate together | Look at the crystal |

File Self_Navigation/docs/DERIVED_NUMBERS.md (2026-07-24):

# Derived numbers

AUTO-GENERATED by tools/generate_config.py from robot.yaml -- DO NOT EDIT

> ## :rotating_light: Revision 2 -- rebuilt from MEASURED hardware
> Revision 1 used `wheel_radius 0.19` and `wheel_separation 0.30`. **Both were
> wrong.** Every velocity, every Nav2 threshold and the whole URDF were wrong
> with them.
>
> | | Rev 1 (wrong) | **Measured** | Error |
> |---|---|---|---|
> | wheel radius | 0.1900 m | **0.0336 m** | **5.65x too big** |
> | wheel separation | 0.3000 m | **0.400 m** | **33% too small** |
> | robot radius | 0.1900 m | **0.210 m** | wheels stick out past the body |

## Inputs (`robot.yaml`)

| | |
|---|---|
| wheel radius | **0.0336 m** (67.2 mm diameter, with rubber) |
| wheel separation | **0.400 m** (centre-to-centre) |
| robot radius | **0.210 m** -- the WHEELS are the widest part, not the body |
| body radius | 0.190 m (visual only) |
| motor | 200 steps/rev x 16 microstep x 1.0 gear |
| wheel RPM band | 5.0 .. **20.0** |

## Kinematic envelope

| | |
|---|---|
| steps per wheel rev | **3200** |
| **distance per step** | **0.0660 mm** -- your odometry resolution |
| linear velocity | 0.0176 .. **0.0704 m/s** |
| angular velocity | 0.0880 .. **0.3519 rad/s** |
| linear accel | 0.1407 m/s^2 |
| angular accel | 0.7037 rad/s^2 |
| **180 deg spin in place** | **8.93 s** |
| step rate cap | **1066 sps** |

## :rotating_light: The RPM cap is the single biggest cost in the project

| RPM | speed | step rate | % of pulse engine |
|---|---|---|---|
| 20 | 0.070 m/s | 1066 sps | 5.3 % |
| 40 | 0.141 m/s | 2133 sps | 10.7 % |
| 60 | 0.211 m/s | 3200 sps | 16.0 % |
| 80 | 0.281 m/s | 4266 sps | 21.3 % |
| 100 | 0.352 m/s | 5333 sps | 26.7 % |

At **20 RPM** the pulse engine is **5.3% used** and the motors have
**12x torque margin**. The cap is buying you nothing.
Change `limits.max_wheel_rpm` in `robot.yaml` and re-run this script -- the entire
stack (firmware clamps, ros2_control, Nav2, velocity_smoother) retunes itself.

## Torque check (6.0 kg robot)

| | |
|---|---|
| motor holding torque | 0.4 N.m **(UNVERIFIED -- get your motor's datasheet)** |
| force per wheel | 0.4 / 0.0336 = **11.9 N** |
| total available | **23.8 N** |
| force needed at 6.0 kg | 2.02 N |
| torque needed per wheel | **0.0340 N.m** |
| **margin** | **11.8x** |
| theoretical max mass | 71 kg (torque-limited) |
| traction ceiling | ~25 N |
| **actually limited by** | **MOTOR TORQUE** |

Small wheels **multiply force** (`F = torque / radius`). This is exactly why
6.0 kg is comfortable on 67 mm wheels and would have been
*impossible* on the 380 mm wheels of revision 1.

## DDS pulse-engine invariant

| | |
|---|---|
| ISR rate | 40000 Hz |
| ceiling (ISR/2) | 20000 sps |
| used | **5.3 %** |

Staying below ISR/2 makes it *arithmetically impossible* for two step pulses to
land on consecutive ticks -- which is what guarantees the DRV8825 its 1.9 us
minimum LOW time. This script **refuses** to emit a config that breaks it.

## Cleaning geometry -- YOUR REAL BRUSHES

Two brushes, 100 mm diameter, centres 200 mm apart.

| | |
|---|---|
| left brush covers | -0.150 .. -0.050 m |
| right brush covers | +0.050 .. +0.150 m |
| **total swept width** | **0.30 m** |
| **gap in the middle** | **0.10 m** |
| lane spacing | 0.190 m |
| lane overlap | 11.0 cm per pass |

> ### :warning: CONFIRM THE 100 mm MIDDLE GAP
> This is fine **only if your suction inlet sits there** (side brushes sweeping
> debris inward is the standard design). If there is nothing in the middle, you
> have a 100 mm uncleaned stripe down the centre of **every lane**, and
> no path planner can fix it.

> ### :warning: THE 9 cm WALL STRIP -- a mechanical limit, not a software one
> The robot centre can never get closer than **0.240 m** to a wall
> (the wheels are the widest part). The brush reaches 0.150 m beyond
> that -- so it stops **9 cm short of every wall**.
>
> Options: accept it; reduce `safety_margin` 0.03 -> 0.01 (strip becomes
> 7 cm); or mount the brushes further outboard.

## Navigation geometry

| | |
|---|---|
| erosion radius | 0.240 m |
| **min passable gap** | **0.480 m** -- narrower doorways are UNREACHABLE |
| costmap inflation | 0.240 m |
| lidar z (from base_link) | **0.2164 m** (= 0.250 from ground - 0.0336 axle height) |
| imu z (from base_link) | 0.0264 m |

## Where these land

| Number | Consumer |
|---|---|
| `MB_MAX_STEP_RATE`, `MB_MAX_ACCEL_SPS2`, `MB_MAX_JERK_SPS3` | `stm32/Core/Inc/minibot_config.h` |
| `wheel_radius`, `wheel_separation` | `diff_drive_controller` (odometry), `base.xacro` |
| `v_max`, `w_max`, `a_max` | `diff_drive_controller`, Nav2 `FollowPath`, `velocity_smoother`, `behavior_server` |
| `robot_radius`, `inflation_radius` | Nav2 global + local costmaps |
| `erode_radius`, `lane_spacing`, `head_width` | `minibot_coverage` planner |
| `lidar_z`, `imu_z` | `lidar.xacro`, `imu.xacro` |

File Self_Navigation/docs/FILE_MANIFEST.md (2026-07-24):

# File manifest

For every file: **why it exists · who calls it · what depends on it · when it runs**.

## Root

| File | Why · Who · When |
|---|---|
| `robot.yaml` | **THE SINGLE SOURCE OF TRUTH.** All geometry and limits. Read by `tools/generate_config.py` only. Never read at runtime. |
| `tools/generate_config.py` | Derives every number in the project from `robot.yaml`. Run manually after any geometry change. `--check` mode exits 1 if generated files are stale. |
| `tools/setup_pi.sh` | One-shot Pi 5 install: apt packages, source deps, udev, colcon build. Run once. |

## `stm32/` — firmware

| File | Why · Who calls it · When |
|---|---|
| `minibot.ioc` | CubeMX project. Optional — the tree builds with plain `make`. Provided so you can regenerate peripherals if you prefer the GUI. |
| `Makefile` | `make` / `make flash` / `make dfu` / `make size`. |
| `STM32F407VETX_FLASH.ld` | 512 K flash @ 0x08000000, 128 K RAM @ 0x20000000, 64 K CCM. Caps the heap below the stack so a runaway alloc fails cleanly instead of corrupting step-engine state. |
| `Core/Inc/minibot_config.h` | **GENERATED.** Every tuning constant. Do not hand-edit. |
| `Core/Src/main.c` | `main()`, `SystemClock_Config()` (168 MHz), and the three HAL callbacks that bridge into the motion core. |
| `Core/Src/gpio.c` | `MX_GPIO_Init()`. Called **first** among peripherals — it drives nENABLE HIGH so the motors are dead before anything else can twitch. |
| `Core/Src/tim.c` | `MX_TIM7_Init()`. PSC=83, ARR=24 → 40 kHz. Started by `MB_Init()`. |
| `Core/Src/usart.c` | `MX_USART1_UART_Init()`. PA9/PA10, 115200 8N1, RX interrupt. |
| `Core/Src/stm32f4xx_hal_msp.c` | Peripheral clocks, AF pins, **NVIC priorities** (TIM7=0, USART1=1). Called from inside `HAL_*_Init()`. |
| `Core/Src/stm32f4xx_it.c` | Vector handlers. Fault handlers **kill the motors then hang**. |
| `Core/Src/minibot_motion.c` | The three-layer step engine. `MB_StepISR()` runs at 40 kHz from TIM7; `MB_Task()` runs in the main loop. |
| `Core/Src/minibot_protocol.c` | CRC-8 framing. `MB_ProtoRxByte()` runs inside the USART1 ISR. |
| `Core/Src/syscalls.c` / `sysmem.c` | newlib stubs. Never called in practice; the linker demands the symbols. |
| `Drivers/` | Official ST HAL + CMSIS, trimmed to the modules we compile. |

## `ros2_ws/src/minibot_hardware/` — the ros2_control plugin

| File | Why · Who calls it · When |
|---|---|
| `stepper_diffdrive.{hpp,cpp}` | Replaces `diffdrive_arduino`, whose protocol is built entirely around quadrature encoders and PID — there is no parameter that makes it work here. Loaded by `controller_manager` from the `<ros2_control>` block in the URDF. `read()`/`write()` at 50 Hz. |
| `serial_link.hpp` | Header-only POSIX termios + CRC-8. Deliberately no `serial` package dependency. |
| `test/test_protocol.cpp` | Pins the CRC known-answer vectors against the firmware. If these ever diverge, the STM32 silently rejects every command and you debug Nav2 for a day. `colcon test`. |
| `minibot_hardware.xml` | pluginlib manifest. |

## `ros2_ws/src/minibot_description/`

| File | Why |
|---|---|
| `urdf/base.xacro` | 380 mm circular body. `base_link` = centre of rotation = centre of the disc. |
| `urdf/lidar.xacro` | RPLIDAR C1, **centred at x=0, y=0**. Off-centre means every in-place turn sweeps the scan origin in a circle, and any frame error goes straight into yaw. |
| `urdf/imu.xacro` | MPU6050 frame. |
| `urdf/ros2_control.xacro` | Binds joints → the STM32 plugin. `steps_per_rev` here **must equal** `MB_STEPS_PER_REV` in the firmware. |
| `rviz/navigation.rviz` | Includes `/particlecloud`. **Watch it** — if it stays spread out, AMCL has not converged and you must not start the run. |

## `ros2_ws/src/minibot_imu/`

| File | Why · When |
|---|---|
| `mpu6050_node.py` | I²C driver → `/imu/data_raw`. `orientation_covariance[0] = -1` (ROS for "no orientation here") — Madgwick supplies it downstream so two filters never fight over the same quantity. Publishes `/diagnostics`. 100 Hz. |
| `imu_calibrate.py` | **Standalone, no ROS.** `--axis-check` walks you through determining `axis_map`. Run before you trust the EKF: an inverted z-axis makes the EKF confidently fuse a heading that turns the wrong way. |
| `config/ekf.yaml` | robot_localization. Fuses `vx` (trustworthy — a literal pulse count) and `vyaw` from the gyro (which doesn't care about wheel slip). **Sole publisher of `odom → base_link`.** |
| `config/imu_params.yaml` | Driver + Madgwick params. `gain: 0.1` leans deliberately toward the gyro — the accelerometer is the noisy one on a robot with motors next to the IMU. |

## `ros2_ws/src/minibot_navigation/`

| File | Why |
|---|---|
| `config/nav2_params.yaml` | AMCL (alphas tuned for open-loop steppers) + RegulatedPurePursuit + keepout filter. **All velocity numbers generated.** |
| `config/keepout_params.yaml` | Costmap filter servers. Only possible because the map is frozen. |
| `config/slam_mapping.yaml` | Phase 1 only. `minimum_travel_heading: 0.10` (stock is 0.5) — this robot spins in place, travelling 0 m, and the stock threshold would never trigger a scan-match during a turn. |
| `behavior_trees/navigate_through_poses_coverage.xml` | **No Spin in recovery.** A Spin pushes the robot off the lane it is mid-way through sweeping; Nav2 replans from the new pose and carries on, leaving an uncleaned stripe that nothing reports. |
| `behavior_trees/navigate_to_pose_dock.xml` | Spin **is** allowed here — no lane is being swept. |

## `ros2_ws/src/minibot_coverage/`

| File | Why · When |
|---|---|
| `prepare_map.py` | **OFFLINE, on your laptop.** Clean → QA → plan → render. The most important tool in the project. A mistake caught here costs a re-run of a script; the same mistake on the floor costs a robot wedged behind the sofa. |
| `coverage_server.py` | **Deliberately dumb.** Plays back the frozen path. Checkpoints after every chunk (resumable). Returns to dock. Services: `/coverage/{start,stop,skip,dock}`. |

## `ros2_ws/src/minibot_bringup/`

| File | Why · When |
|---|---|
| `launch/robot.launch.py` | Hardware layer. Always running. |
| `launch/map.launch.py` | Phase 1. Once. |
| `launch/clean.launch.py` | Phase 3. AMCL + Nav2 + keepout + coverage. **On the Pi.** |
| `launch/rviz.launch.py` | Laptop. Viewing + manual override only — **no autonomy**, so a Wi-Fi drop doesn't stop the robot mid-run. |
| `scripts/stm32_bench.py` | **RUN THIS FIRST.** No ROS. If this doesn't work, nothing above it will, and you'll waste a day blaming Nav2 for a swapped TX/RX pair. |
| `scripts/calibrate_odom.py` | Empirically fixes `wheel_radius` then `wheel_separation`. Listens to `/diff_drive_controller/odom`, **not** `/odom` — calibrating against the EKF means calibrating the wheels against the filter that's compensating for them. |
| `config/controllers.yaml` | `enable_odom_tf: false` — the EKF owns that TF. |
| `udev/99-minibot.rules` | Names the LIDAR's USB-serial device (assigned in enumeration order otherwise). The STM32 link is now GPIO UART (`/dev/ttyAMA0`, fixed by hardware, no udev rule needed) rather than a second USB-serial device. |
| `systemd/*.service` | `minibot-clean` is **not** enabled by default and does **not** auto-start the run. A robot that starts driving before anyone confirmed AMCL converged is a robot that drives into a wall. |

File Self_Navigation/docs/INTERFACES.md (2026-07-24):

# Interfaces — topics, services, actions, frames, packets

## Topics

| Topic | Type | Published by | Consumed by |
|---|---|---|---|
| `/scan` | `sensor_msgs/LaserScan` | `sllidar_ros2` | AMCL, both costmaps, slam_toolbox, collision_monitor |
| `/imu/data_raw` | `sensor_msgs/Imu` | `mpu6050_node` | `imu_filter_madgwick` |
| `/imu/data` | `sensor_msgs/Imu` | `imu_filter_madgwick` | `ekf_filter_node` |
| `/imu/temperature` | `sensor_msgs/Temperature` | `mpu6050_node` | diagnostics |
| `/diff_drive_controller/odom` | `nav_msgs/Odometry` | `diff_drive_controller` | `ekf_filter_node`, `calibrate_odom.py` |
| `/diff_drive_controller/cmd_vel` | `geometry_msgs/TwistStamped` | `twist_mux` | `diff_drive_controller` |
| `/odom` | `nav_msgs/Odometry` | `ekf_filter_node` | Nav2, `velocity_smoother` |
| `/joint_states` | `sensor_msgs/JointState` | `joint_state_broadcaster` | `robot_state_publisher` |
| `/nav_vel` | `TwistStamped` | `twist_stamper` | `twist_mux` (priority 10) |
| `/joy_vel` | `TwistStamped` | teleop | `twist_mux` (**priority 100** — a human always wins) |
| `/cmd_vel_smoothed` | `geometry_msgs/Twist` | `velocity_smoother` | `twist_stamper` |
| `/map` | `nav_msgs/OccupancyGrid` | `map_server` (latched) | AMCL, global costmap, `coverage_server` |
| `/particlecloud` | `geometry_msgs/PoseArray` | AMCL | **you, in RViz** |
| `/coverage_path` | `nav_msgs/Path` (latched) | `coverage_server` | RViz |
| `/coverage_map` | `OccupancyGrid` (latched) | `coverage_server` | RViz — cleaned (light) vs to-do (dark) |
| `/coverage_progress` | `std_msgs/Float32` | `coverage_server` | you |
| `/diagnostics` | `diagnostic_msgs/DiagnosticArray` | IMU, coverage | `diagnostic_aggregator` |
| `/costmap_filter_info` | `nav2_msgs/CostmapFilterInfo` | `costmap_filter_info_server` | both costmaps |
| `/keepout_filter_mask` | `OccupancyGrid` | `keepout_filter_mask_server` | keepout filter |

## Services

| Service | Type | Provided by | What it does |
|---|---|---|---|
| `/coverage/start` | `std_srvs/Trigger` | `coverage_server` | begin (or resume) the run |
| `/coverage/stop` | `std_srvs/Trigger` | `coverage_server` | abort — **resumable**, checkpoint is kept |
| `/coverage/skip` | `std_srvs/Trigger` | `coverage_server` | robot is wedged; skip this chunk and carry on |
| `/coverage/dock` | `std_srvs/Trigger` | `coverage_server` | go home now |
| `/imu/recalibrate` | `std_srvs/Trigger` | `mpu6050_node` | re-measure gyro bias (**hold the robot still**) |
| `/{local,global}_costmap/clear_entirely_*` | `nav2_msgs/ClearEntireCostmap` | Nav2 | used by the BT recovery |

## Actions

| Action | Type | Server | Client |
|---|---|---|---|
| `navigate_through_poses` | `nav2_msgs/NavigateThroughPoses` | `bt_navigator` | `coverage_server` (12 waypoints per goal) |
| `navigate_to_pose` | `nav2_msgs/NavigateToPose` | `bt_navigator` | `coverage_server` (docking), RViz |

## TF frames

| Frame | Parent | Published by |
|---|---|---|
| `map` | — | AMCL (phase 3) / slam_toolbox (phase 1) |
| `odom` | `map` | ↑ same |
| `base_link` | `odom` | **`ekf_filter_node` — SOLE PUBLISHER** |
| `base_footprint` | `base_link` | `robot_state_publisher` (static) |
| `body`, `left_wheel`, `right_wheel`, `caster_*` | `base_link` | `robot_state_publisher` |
| `lidar_frame` | `base_link` | `robot_state_publisher` (static) |
| `imu_link` | `base_link` | `robot_state_publisher` (static) |

## UART packets

Frame: `$<PAYLOAD>*<CRC8_HEX><LF>` — CRC-8/ATM (poly `0x07`, init `0x00`) over
PAYLOAD only. `$` **always** restarts the parser, which is what lets it
resynchronise after line noise instead of wedging.

### Pi → STM32

| Packet | Meaning |
|---|---|
| `$V,<l_sps>,<r_sps>*XX` | signed steps/second target. Clamped to ±1066 on both sides. |
| `$E,1*XX` / `$E,0*XX` | energise / de-energise the drivers |
| `$S*XX` | **EMERGENCY STOP** — bypasses the ramp entirely |
| `$R*XX` | zero the step counters |
| `$P*XX` | ping → `$K*XX` |

### STM32 → Pi, at 50 Hz

```
$F,<l_steps>,<r_steps>,<l_sps>,<r_sps>,<flags>,<seq>*XX
```

| Field | Meaning |
|---|---|
| `l_steps` / `r_steps` | int32, signed, cumulative. **THIS IS YOUR ODOMETRY.** |
| `l_sps` / `r_sps` | the *actual* current step rate, post-profile |
| `flags` | bitfield, below |
| `seq` | uint16, wraps. Lets the Pi **detect dropped frames** rather than silently interpolating across them. |

| Flag | Value | Meaning |
|---|---|---|
| `ENABLED` | 1 | drivers energised |
| `ESTOP` | 2 | emergency stop latched |
| `CMD_TIMEOUT` | 4 | the Pi went quiet for >500 ms; motors stopped |
| `CRC_ERR` | 8 | at least one corrupt frame since boot → **check your cable/grounding** |
| `OVERRUN` | 16 | UART overrun since boot |
| `CLAMPED` | 32 | a command exceeded the RPM cap → **your limits disagree somewhere; run `generate_config.py`** |

### Verified CRC vectors

| Payload | CRC |
|---|---|
| `V,1000,-1000` | `0x47` |
| `F,12345,-6789,500,-500,33,7` | `0x31` |

Firmware C, ROS 2 C++ (`serial_link.hpp`), and the Python bench tool were tested
against each other and **agree bit-for-bit**.

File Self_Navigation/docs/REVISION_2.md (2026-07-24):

# Revision 2 — what changed, and why Revision 1 was wrong

## The error

Revision 1 was built on **wheel_radius = 0.190 m** and **wheel_separation = 0.300 m**.
Both were wrong.

| | Rev 1 | Measured | Error |
|---|---|---|---|
| wheel radius | 0.1900 m | **0.0336 m** | **5.65× too big** |
| wheel separation | 0.3000 m | **0.400 m** | **33 % too small** |
| robot radius | 0.1900 m | **0.210 m** | wheels stick out past the body |

## Why the "physics check" failed — this was a reasoning error, not just bad input

Revision 1 contained this argument:

> *"The 5–20 RPM band only makes physical sense with large wheels — small wheels
> would give 1.8–7.1 cm/s, which is absurdly slow. Therefore the wheels must be
> large."*

**The wheels are small.** So the correct conclusion was never *"the wheels are
large."* It was:

> **"The 20 RPM cap is the number that's wrong."**

Given a contradiction between two inputs, I picked the wrong one to distrust —
and then built 336 files on top of that choice. The lesson is encoded in the
tooling now: `generate_config.py` **warns** whenever the pulse engine is under
15 % utilised *and* torque margin is high, because that combination means an
artificial speed cap is throttling the robot.

## What every wrong number caused

| Consequence | Rev 1 | Rev 2 |
|---|---|---|
| `v_max` (20 RPM) | 0.3979 m/s | **0.0704 m/s** |
| `omega_max` | 2.6529 rad/s | **0.3519 rad/s** |
| 180° spin | 1.18 s | **8.93 s** |
| distance per step | 0.3731 mm | **0.0660 mm** |
| Nav2 `robot_radius` | 0.190 | **0.210** |
| Nav2 `inflation_radius` | 0.22 | **0.24** |
| min passable gap | 0.44 m | **0.48 m** |
| 49 m² flat | 16 min | **94 min** |

## Nav2 parameters that were ACTIVELY BROKEN

These would not merely have been suboptimal — the robot would not have worked:

| Parameter | Rev 1 | Problem | Rev 2 |
|---|---|---|---|
| `min_theta_velocity_threshold` | 0.30 | `omega_max` is only **0.352** → Nav2 would classify **every rotation the robot can perform** as "stopped". **It would never turn.** | **0.050** |
| `min_x_velocity_threshold` | 0.05 | `v_max` is only **0.070** → 71 % of the speed range written off as "stopped" | **0.010** |
| `rotate_to_heading_angular_vel` | 2.20 | **6.3× over** the physical maximum | **0.2991** |
| `lookahead_dist` | 0.40 m | at 0.070 m/s that is **5.7 seconds** ahead — would smooth straight through the lane-end turns coverage depends on | **0.20 m** |
| `movement_time_allowance` | 30 s | a 180° turn now takes **8.9 s** with zero linear progress | **45 s** |
| `robot_radius` | 0.19 | ignores that the **wheels** are the widest part | **0.210** |

## The good news — torque

Small wheels **multiply force** (`F = torque / radius`):

| | Rev 1 (0.190 m wheels) | Rev 2 (**0.0336 m wheels**) |
|---|---|---|
| force per wheel @ 0.40 N·m | 2.1 N | **11.9 N** |
| torque needed for 6 kg | 0.565 N·m | **0.034 N·m** |
| **verdict** | **IMPOSSIBLE** (40 % short) | **~12× margin** |

**6 kg was impossible on the wheels I assumed. It is comfortable on your real
wheels.** So is 10 kg. The binding constraint is now traction, not torque.

## What did NOT change

**The firmware.** `MB_MAX_STEP_RATE` is still 1066 sps, because step rate depends
only on RPM and microstepping — **not on wheel size**. The wheel radius only
determines how much *distance* those steps produce. Only the informational
`MB_WHEEL_RADIUS_M` / `MB_WHEEL_SEP_M` constants moved.

That is a direct benefit of having put every derived number behind one generator.

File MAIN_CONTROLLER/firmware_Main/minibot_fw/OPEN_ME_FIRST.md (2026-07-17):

# minibot_fw — STM32F407VET6 firmware

**Status: VERIFIED. This compiles clean with arm-none-eabi-gcc 13.2.1.**
0 errors, 0 warnings in project code. 19,104 B flash (3.7% of 512 KB).

The project is now named **`minibot_fw`** (was `Minibot_v6_rev2_STM`).
That rename is deliberate — see "Why your import failed" below.

---

## Fastest path: flash it NOW, no IDE

The compiled firmware is already in `prebuilt/`. You do not need CubeIDE
to get the robot moving.

```bash
# ST-LINK
st-flash --reset write prebuilt/minibot.bin 0x8000000

# or, with the ST tool
STM32_Programmer_CLI -c port=SWD -w prebuilt/minibot.hex -rst
```

Then bench-test it (robot on blocks, no ROS):
```bash
python3 stm32_bench.py --watch          # expect $F,... frames at ~50 Hz
python3 stm32_bench.py --verify-steps   # commands exactly 1 wheel revolution
```

## Rebuild from source, no IDE

```bash
make            # -> build/minibot.elf .hex .bin
make flash
```
Needs only `gcc-arm-none-eabi`. This is the build I ran and verified.

---

## Importing into STM32CubeIDE

### Why your import failed before

The error was **"already exist in the workspace OR project description
file is corrupted."** It was the FIRST half, not the second.

Proof: the Import dialog *listed the project in the Projects box*. Eclipse
can only do that by successfully parsing `.project`. A corrupt description
file would not have appeared at all.

What actually happened: you launched CubeIDE with the **extracted project
folder itself as the workspace** (the title bar read `Minibot_v6_rev2_STM`
— that is the workspace name). Eclipse cannot import a project that lives
at the workspace root. The names collided.

Renaming the project to `minibot_fw` removes the collision no matter what
your workspace is called.

### Import steps

1. **File -> Switch Workspace -> Other...**
   Pick a folder that is NOT this project, e.g. `~/STM32CubeIDE/workspace`
2. **File -> Import -> General -> Existing Projects into Workspace**
3. Root directory: the folder containing this file (`minibot_fw/`)
4. `minibot_fw` appears checked -> **Finish**
5. Ctrl+B to build

**Golden rule:** workspace folder and project folder must be two different
places. Never open a project folder as a workspace.

### If CubeIDE still fights you

Skip its managed build entirely — the Makefile is right there and it works:

**File -> Import -> C/C++ -> Existing Code as Makefile Project**
- Location: this folder
- Toolchain: **Cross ARM GCC**
- Finish

You get the editor and debugger; `make` does the building.

---

## Hardware this expects

| | |
|---|---|
| MCU | STM32F407VET6 |
| UART to Pi | USART1 — **PA9 = TX, PA10 = RX**, 115200 8N1 |
| Step engine | TIM7 ISR @ 40 kHz (DDS phase accumulator) |
| Shared ENABLE | **PE3** (both DRV8825 nENABLE, active LOW) |
| LEFT STEP / DIR | **PE4 / PE5** |
| RIGHT STEP / DIR | **PE6 / PE7** |

Pi TX -> PA10, Pi RX -> PA9, **and a common GND**. TX/RX cross over.

## Layout

```
minibot_fw/
├── .project .cproject .mxproject .settings/   CubeIDE metadata
├── minibot_fw.ioc            open in CubeMX
├── minibot_fw.launch         ST-LINK debug config
├── Makefile                  verified working build
├── STM32F407VETX_FLASH.ld
├── prebuilt/                 minibot.hex / .bin / .elf  <- FLASH THESE
├── Core/
│   ├── Inc/  main, gpio, tim, usart, stm32f4xx_hal_conf, stm32f4xx_it,
│   │         minibot_config.h, minibot_motion.h, minibot_protocol.h
│   ├── Src/  main.c, gpio.c, tim.c, usart.c, hal_msp, it, system,
│   │         syscalls, sysmem, minibot_motion.c, minibot_protocol.c
│   └── Startup/startup_stm32f407xx.s
└── Drivers/  STM32F4xx_HAL_Driver + CMSIS
```

**Your code lives in `minibot_motion.c`, `minibot_protocol.c`, and
`minibot_config.h`.** Everything else is CubeMX-generated or ST vendor code.
CubeMX regeneration will not touch those three files.

---

## Before you trust the distances it drives

`minibot_config.h` assumes **200 steps/rev x 16 microstep = 3200 steps per
wheel revolution**, and **67.2 mm wheels**. If your DRV8825 jumpers are
actually 1/8, or the motors are 0.9 deg/step, **every distance is silently
2x wrong** and nothing will tell you.

`stm32_bench.py --verify-steps` commands exactly one wheel revolution
(= 211 mm of travel on 67.2 mm wheels). Mark the wheel and the floor.
Run it before you trust anything.

---

## Fix applied 2026-07-13: CubeIDE build error (DAP_config.h not found)

CubeIDE's managed build auto-discovers every `.c` file under `Drivers/`,
unlike the Makefile which only compiles a fixed list. The vendored CMSIS
repo had extra folders that were never part of this project:

- `Drivers/CMSIS/DAP/` — ST's CMSIS-DAP USB debug-probe firmware, needs a
  `DAP_config.h` that was never included -> fatal error in CubeIDE only
- `Drivers/CMSIS/Core/`, `Drivers/CMSIS/Core_A/` — Cortex-M template /
  Cortex-A variants, irrelevant to the F407 (Cortex-M4)
- `Drivers/STM32F4xx_HAL_Driver/Src/Legacy/*.c` (CAN, ETH) — not used by
  this firmware, not in the Makefile's source list either

All of the above are now deleted. `Drivers/` contains exactly the 22 `.c`
files the Makefile always compiled, plus only the headers actually
included. Verified: `find Core Drivers -name "*.c"` now returns exactly
the Makefile's `C_SOURCES` list, and `make` still produces the identical
19,104-byte binary. CubeIDE's build should now match the Makefile build.

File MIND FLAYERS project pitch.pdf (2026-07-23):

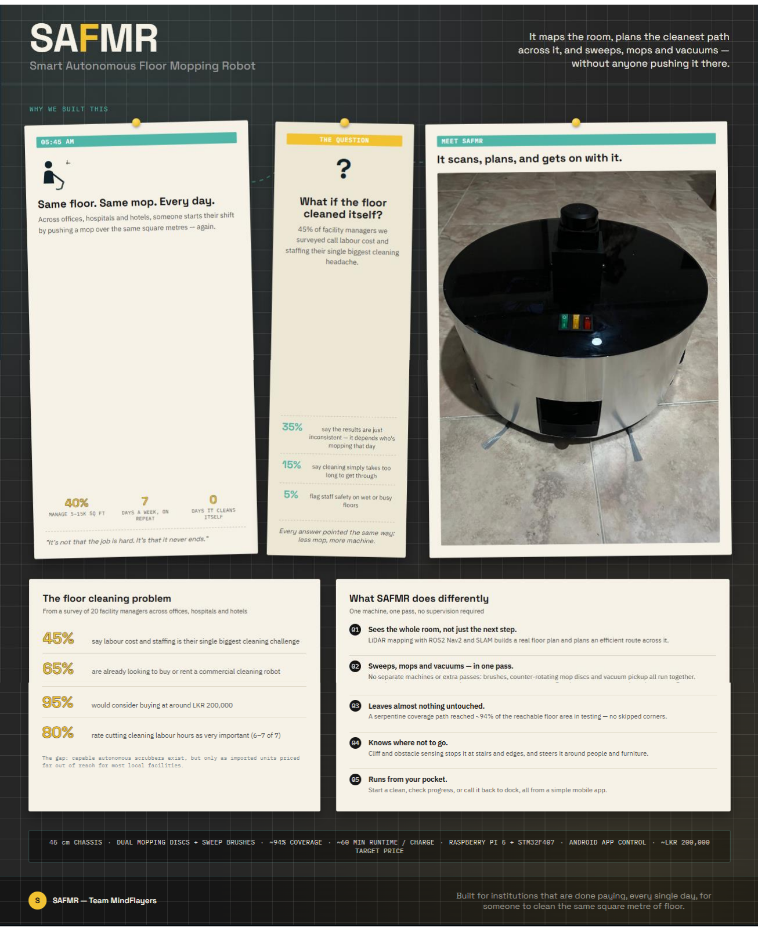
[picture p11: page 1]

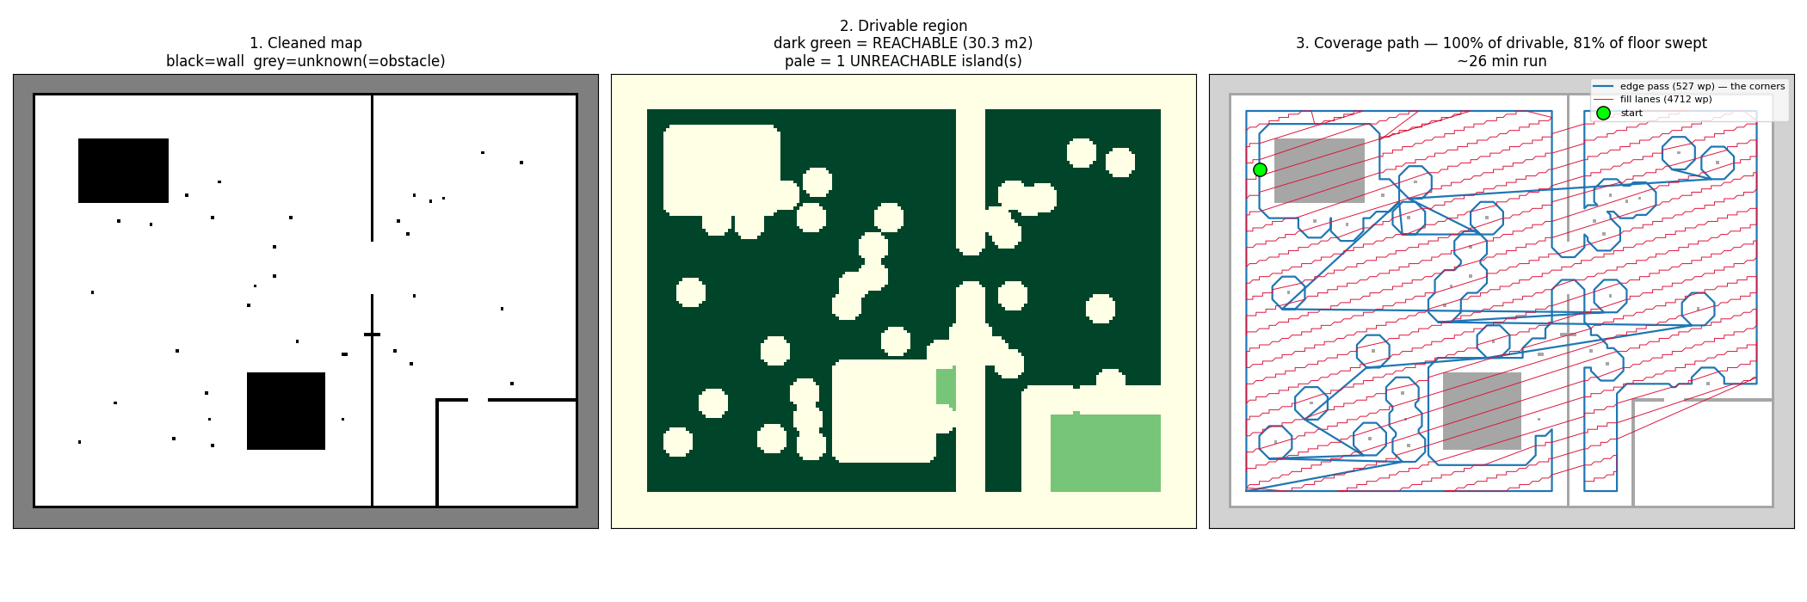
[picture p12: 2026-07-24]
Self_Navigation/docs/example_coverage_preview.png

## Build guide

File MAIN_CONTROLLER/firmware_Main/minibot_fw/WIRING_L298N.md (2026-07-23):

# L298N DC-motor wiring — minibot (STM32F407VET6)

4 brushed DC motors, 2× L298N, 12 V supply. Direction is fixed in firmware:
on **each** driver one motor runs **CW** and the other **CCW**.

Only 8 pins were free, and all 8 are used as L298N `IN` lines. There is **no
spare pin for the enable inputs**, so on each driver the tied-together
`ENA+ENB` node must sit at **+5 V** (both channels permanently enabled).
Direction / stop is done entirely with the `IN` pins.

---

## 1. Signal wiring — STM32 → L298N IN pins

### Driver 1  (Motors 1 & 2)
| STM32 pin | L298N IN | Motor / output | Fixed direction |
|---|---|---|---|
| PD0 | IN1 | Motor 1 (OUT1/OUT2) | CW  → IN1=H, IN2=L |
| PD1 | IN2 | Motor 1 | |
| PD2 | IN3 | Motor 2 (OUT3/OUT4) | CCW → IN3=L, IN4=H |
| PD3 | IN4 | Motor 2 | |

### Driver 2  (Motors 3 & 4)
| STM32 pin | L298N IN | Motor / output | Fixed direction |
|---|---|---|---|
| PA2 | IN1 | Motor 3 (OUT1/OUT2) | CW  → IN1=H, IN2=L |
| PA3 | IN2 | Motor 3 | |
| PE14 | IN3 | Motor 4 (OUT3/OUT4) | CCW → IN3=L, IN4=H |
| PE15 | IN4 | Motor 4 | |

The STM32 outputs 3.3 V logic. The L298N inputs are TTL and read 3.3 V as a
solid HIGH (input-high threshold ≈ 2.3 V), so **no level shifter is needed**.

---

## 2. Enable pins (ENA + ENB)  — the important part

On each L298N you have tied `ENA` and `ENB` together. That combined node must
be held at **+5 V** so both channels are always enabled. Two equivalent ways:

- **Easiest:** keep **both** on-board `ENA` and `ENB` jumper caps installed.
  Each cap ties its enable to the board's internal +5 V — done.
- **If you removed the caps** and soldered ENA↔ENB together: run **one wire**
  from that combined node to the board's **+5 V** pin.

There is no PWM speed control in this build (enable is fixed HIGH). The motors
run at whatever speed the 12 V rail gives. See §5 if you want speed control.

---

## 3. Power wiring  (do this carefully — grounding is the #1 mistake)

For **each** L298N:

| L298N terminal | Connect to |
|---|---|
| `+12V` (motor supply) | 12 V battery **+** |
| `GND` | 12 V battery **−**  **and**  STM32 GND (shared) |
| `+5V` | leave the 5V-EN jumper **ON** → this pin is the board's own regulated 5 V, used internally for the ENA/ENB caps. Do **not** wire it to any other 5 V source. |

**Common ground is mandatory.** The STM32 GND, both L298N GND terminals, and
the 12 V battery minus must all be joined. Without a shared ground the IN
signals have no reference and the motors behave randomly or not at all.

Do **not** power the STM32 board from the L298N +5 V unless that is genuinely
your only supply and you understand the current budget — keep the STM32 on its
own USB / 5 V supply and just share ground.

```
                 12 V battery
                  +        -
                  |        |
        +---------+        +----------------+-----------------+
        |                                   |                 |
   [L298N #1 +12V]                     [L298N #1 GND]   [L298N #2 GND]---+
   [L298N #2 +12V]                          |                            |
                                            +-------- STM32 GND ---------+
                                                     (common ground)
```

---

## 4. Motor output wiring & direction

- Driver 1: **OUT1/OUT2 → Motor 1**, **OUT3/OUT4 → Motor 2**
- Driver 2: **OUT1/OUT2 → Motor 3**, **OUT3/OUT4 → Motor 4**

"CW" / "CCW" are only labels — real spin direction depends on which way you
land the two motor leads on `OUTx`. **If a motor spins the wrong way**, either
swap its two output wires, or swap `DCM_CW`/`DCM_CCW` for that motor in
`Core/Src/minibot_dcmotor.c` (function `DCM_Run`).

---

## 5. Firmware hooks (already in the project)

- `Core/Inc/minibot_dcmotor.h`, `Core/Src/minibot_dcmotor.c` — the module.
- `main()` calls `DCM_Init()` (pins → outputs, all stopped) then `DCM_Run()`
  (applies M1 CW, M2 CCW, M3 CW, M4 CCW). Comment out `DCM_Run()` to leave the
  motors stopped at boot.
- `DCM_Set(DCM_MOTOR_2, DCM_STOP)` etc. lets you drive any motor individually.
- The stepper code, UART protocol, TIM7 and all original pins are untouched.

### If you later want speed control
You'd need to free a pin per driver for a PWM enable line: stop tying ENA/ENB
to 5 V, feed the combined ENA/ENB from a timer PWM output instead, and keep the
IN pins for direction. That needs 2 more pins than are currently free, so it
would mean giving up one of the existing functions or moving to a board with
more free pins.

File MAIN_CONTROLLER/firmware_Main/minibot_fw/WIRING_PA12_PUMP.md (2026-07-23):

# PA12 pump switch — low-side IRLZ44N (STM32F407VET6)

Firmware drives PA12: **HIGH 3 s (pump ON), LOW 5 s (pump OFF)**, forever.
PA12 → MOSFET gate → pump switches on and off. This is a low-side switch
(load on the high side, MOSFET between load and ground).

## Correct connections

```
        +12V ─────────────┬──────────────► pump (+)
                          │
                     (cathode)
                       1N4007          ◄── flyback diode ACROSS the pump
                      (anode)
                          │
        pump (−) ─────────┴───────────┬──► IRLZ44N DRAIN
                                      │
   PA12 ──[220 Ω]──┬── IRLZ44N GATE   │
                   │                  │
                [10 kΩ]           IRLZ44N SOURCE ──► GND
                   │
                  GND

   Common ground: STM32 GND = MOSFET source = 12V supply (−)
```

- **PA12 → 220 Ω → gate:** good. The 220 Ω limits the gate-charge inrush.
- **Gate → 10 kΩ → GND (add this):** a pull-down that holds the MOSFET OFF
  while PA12 is high-impedance (during reset/boot/flashing). Without it the
  pump can twitch on at power-up before firmware runs. Strongly recommended.
- **Drain = pump (−), Source = GND:** correct for a low-side switch.
- **Common ground is mandatory:** STM32 GND, MOSFET source, and the 12 V
  supply minus must all be the same node, or the 3.3 V gate signal has no
  reference and the MOSFET won't switch cleanly.

## The flyback diode — check its placement

It must sit **across the pump**, cathode (stripe) to **+12 V**, anode to the
**pump(−)/drain** node. That gives the motor's coil current a path to
free-wheel when the MOSFET turns off (pump− → diode → +12 V), clamping the
drain spike to ~12.7 V.

A diode from the drain to **ground** (a common miswire) does **not** clamp the
turn-off spike, because it doesn't complete the coil's current loop back to the
+12 V rail — the drain can still fly well above 12 V and stress the MOSFET. If
that's how it's wired now, move the diode across the pump as above.

## IRLZ44N at a 3.3 V gate

The IRLZ44N is a logic-level MOSFET, so 3.3 V does turn it on. But its on-
resistance is specified at Vgs = 5 V / 4 V; at 3.3 V R_DS(on) is a bit higher,
so it runs a little warmer under load. For a small pump this is fine. For a
higher-current pump, either drive the gate at 5 V (e.g. a small
gate-driver/level-shift transistor) or add a heatsink, and keep the gate 220 Ω
where it is.

## Changing the timing

Edit `Core/Src/minibot_signal.c`:

    #define SIG_HIGH_MS   3000u   /* pump ON  time (ms) */
    #define SIG_LOW_MS    5000u   /* pump OFF time (ms) */

The pump starts in the OFF phase at boot (safe). To start with the ON phase
instead, set `s_level = 1` in `Sig_Init()` and drive the pin `GPIO_PIN_SET`
there.

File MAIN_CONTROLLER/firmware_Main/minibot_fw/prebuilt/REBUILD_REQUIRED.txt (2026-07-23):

The old prebuilt binaries (minibot.hex/.bin/.elf) were REMOVED on purpose.

They were built BEFORE the L298N DC-motor code was added, so flashing them
would run the robot with the 4 DC motors dead. Rebuild from source to get a
binary that includes the DC-motor module:

  Option A - STM32CubeIDE:
      File > Open Projects from File System... > select this folder,
      then Project > Build (Ctrl+B). New file Core/Src/minibot_dcmotor.c is
      auto-discovered. Flash the resulting Debug/minibot_fw.elf.

  Option B - Makefile + arm-none-eabi-gcc:
      make            # produces build/minibot.hex / .bin / .elf

Nothing else in the build setup changed.

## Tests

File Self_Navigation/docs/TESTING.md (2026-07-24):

# Testing & troubleshooting

**Do these in order.** Each step depends on the one before. Skipping ahead is how
you spend a day debugging Nav2 for what is a swapped TX/RX pair.

---

## 0. Bench-test the STM32 — NO ROS. Robot on blocks.

```bash
python3 stm32_bench.py --watch
```

**Expect:** `steps L=0 R=0 | sps L=0 R=0 | seq=... | -` at ~50 Hz.

| Symptom | Cause |
|---|---|
| Nothing at all | TX/RX swapped; no common ground; wrong device |
| Garbage bytes | Wrong baud — **or the 25 MHz crystal problem** (see below) |
| `BAD CRC` lines | Noisy cable. Shorten it, ground it, keep it away from motor wires |
| Frames but `CRC_ERR` flag set | Same — the STM32 is rejecting corrupt commands (correctly) |

> ### The 25 MHz crystal trap
> If your board has a 25 MHz crystal (many F407VET6 "black boards" do) and you
> didn't change `HSE_VALUE` + `PLLM`, then your **baud rate and step rate are both
> wrong by the same 25/8 ratio**. The symptom is *garbage on serial AND motors at
> the wrong speed* — two confusing symptoms at once. See `stm32/README.md`.

### Direction check
```bash
python3 stm32_bench.py --left 500 --right 500 --secs 3
```
Both wheels should turn so the robot would go **forward**.

| What happens | Fix |
|---|---|
| Robot would **spin** | flip exactly **ONE** of `MB_LEFT_DIR_INVERT` / `MB_RIGHT_DIR_INVERT` |
| Robot would go **backward** | flip **BOTH** |

Fix it in `robot.yaml` → `firmware.left_dir_invert` / `right_dir_invert`, then
`python3 tools/generate_config.py && cd stm32 && make flash`.

> Fix direction in the **firmware**, not in `ros2_control.xacro`. That way the
> STM32's own step counts are correct even when you drive it from the bench tool.

### Microstep check — this one silently doubles every distance
```bash
python3 stm32_bench.py --verify-steps
```
Commands exactly 3200 steps = **one wheel revolution** at 1/16 microstepping.
One revolution of your 67.2 mm wheel = **211 mm of travel**. Mark the wheel AND
mark the floor — check both.

If the wheel turns **twice**, your DRV8825 jumpers say 1/8, not 1/16. Every
distance the robot ever reports will be off by 2×. Fix the jumpers
(M2=HIGH, M1=LOW, M0=LOW) **or** set `geometry.microstepping: 8` in `robot.yaml`
and regenerate.

---

## 1. IMU

```bash
i2cdetect -y 1                 # MUST show 68
ros2 run minibot_imu imu_calibrate.py
```

**Expect:** `|accel| ≈ 9.81`, gyro noise < 0.05 rad/s, `accel z ≈ +9.81`.

| Symptom | Meaning |
|---|---|
| `accel z` is **negative** | board is upside down → `axis_map: ['x','-y','-z']` |
| `accel z` ≈ 0 | board is on its side/rotated → run `--axis-check` |
| Gyro noise > 0.05 | **the robot moved during calibration** — the bias is garbage and every heading downstream inherits it |

### The axis check that actually matters
```bash
ros2 run minibot_imu imu_calibrate.py --axis-check
```
Rotate the robot **counter-clockwise** (viewed from above). `gyro z` **must go
positive** — that's the ROS convention.

If it's negative and you don't fix it, the EKF will confidently fuse a heading
that turns the **wrong way**. The symptom (a map that tears itself apart during
turns) looks nothing like the cause.

**Fix it in `axis_map`, never in the EKF.** The EKF cannot distinguish a mounting
error from real motion — it will happily fuse your mistake.

---

## 2. TF — exactly ONE publisher on `odom → base_link`

```bash
ros2 launch minibot_bringup robot.launch.py
ros2 run tf2_tools view_frames
ros2 topic echo /tf | grep -A2 base_link      # who is publishing?
```

**If the robot flickers between two poses in RViz, this is why.** Check:

```
diff_drive_controller : enable_odom_tf = false
imu_filter_madgwick   : publish_tf     = false
ekf_filter_node       : publish_tf     = true    ← the only one
```

---

## 3. LIDAR orientation — get this wrong and your map is mirrored

In RViz: fixed frame `odom`, add `LaserScan` on `/scan` and `RobotModel`.

1. Point the robot at a wall. The scan wall must appear **in front of** the robot,
   not behind it. If it's behind → `rpy="0 0 ${pi}"` in `lidar.xacro`.
2. Drive forward slowly. **The walls must stay still in `odom`.** If they smear or
   rotate, your `wheel_radius`/`wheel_separation` are wrong — go to step 4.

A mirrored `lidar_frame` produces a mirrored map, and then Nav2 confidently drives
into walls it believes are behind it.

---

## 4. Odometry calibration — the two numbers everything rests on

**Straight line FIRST.** Rotation error depends on wheel radius, so calibrating
rotation against an uncalibrated radius just moves the error around.

```bash
ros2 run minibot_bringup calibrate_odom.py --straight 2.0
# measure the ACTUAL distance with a tape measure, type it in
```

```bash
ros2 run minibot_bringup calibrate_odom.py --rotate 10
# count the ACTUAL revolutions, type it in
```

Apply the corrections to **`robot.yaml`**, then:
```bash
python3 tools/generate_config.py
cd stm32 && make flash
cd ../ros2_ws && colcon build --symlink-install
```

---

## 5. Map it (phase 1)

```bash
ros2 launch minibot_bringup robot.launch.py     # terminal 1
ros2 launch minibot_bringup map.launch.py       # terminal 2
ros2 run teleop_twist_keyboard teleop_twist_keyboard \
    --ros-args -r /cmd_vel:=/joy_vel            # terminal 3
```

**Drive slowly. CLOSE THE LOOP** — return to where you started before saving.
Without a loop closure, slam_toolbox has no chance to correct accumulated drift
and your map ends up subtly skewed. Every coverage lane inherits that skew.

```bash
ros2 run nav2_map_server map_saver_cli -f ~/ros2_ws/maps/home
```

---

## 6. Plan it — OFFLINE, on your laptop

```bash
python3 prepare_map.py --map maps/home.yaml --start 0 0
```

Then, and this is **not optional**:

1. **Read `maps/home_qa.txt`.** Any unreachable regions? Any corridor narrower
   than 0.44 m?
2. **Open `maps/home_coverage_preview.png` and LOOK AT IT.**

> If the path is wrong on your screen, it will be wrong on your floor. A mistake
> caught here costs a re-run of a script. The same mistake caught on the floor
> costs a robot wedged behind the sofa for 15 minutes.

---

## 7. Clean it

```bash
ros2 launch minibot_bringup clean.launch.py \
    map:=$HOME/ros2_ws/maps/home.yaml \
    path:=$HOME/ros2_ws/maps/home_coverage_path.yaml
```

In RViz: **2D Pose Estimate** at the robot's real pose. Then **check two things
before you start**:

1. **The laser scan lines up with the map walls.**
2. **`/particlecloud` has CONVERGED** — a tight cluster, not a spread-out cloud.
   If it's still spread out, AMCL doesn't know where it is. Do not start the run.

```bash
ros2 service call /coverage/start std_srvs/srv/Trigger
ros2 topic echo /coverage_progress
```

---

## Troubleshooting

| Symptom | Cause | Fix |
|---|---|---|
| Robot flickers between two poses in RViz | Two publishers on `odom → base_link` | §2 |
| Map is mirrored | `lidar_frame` rpy | §3 |
| Robot drives 2× too far | Microstep jumpers say 1/8 | `--verify-steps`, §0 |
| Robot spins instead of driving forward | One DIR inverted | flip **one** `MB_*_DIR_INVERT` |
| `CLAMPED` flag in feedback | Nav2 asking for more than the 20 RPM cap | Your limits disagree somewhere. `generate_config.py` and re-paste **all** of them |
| `CMD_TIMEOUT` flag | Pi went quiet >500 ms | Is `controller_manager` alive? Is the cable seated? |
| `CRC_ERR` flag | Corrupt frames | Cable too long / near the motor wires / no common ground |
| Coverage ends at ~60 % | Nav2 aborted chunks | `grep FAILED` the log. Usually AMCL drift or an obstacle the map doesn't know about |
| Nav2 aborts during every lane-end turn | Progress checker sees the in-place spin as a stall | Already fixed: `required_movement_radius: 0.25`, `movement_time_allowance: 30.0` |
| Edge pass won't plan | `inflation_radius` too big | Must be ~0.22, not Nav2's stock 0.70 |
| Uncleaned stripes between lanes | `lane_spacing` ≥ cleaning head width | Reduce `coverage.lane_spacing` in `robot.yaml` |
| Uncleaned stripe down the **centre** of every lane | The 100 mm gap between your two brushes, with no suction inlet in it | **Mechanical.** Check whether your intake actually sits in that gap |
| Uncleaned **9 cm strip along every wall** | The brush stops short of where the robot can reach | **Mechanical.** Mount brushes further outboard, or accept it |
| Robot never turns at all | `min_theta_velocity_threshold` > `omega_max` | Fixed in Rev 2 (0.050 vs omega_max 0.352). If you raise the RPM cap, regenerate |
| Costmap hangs on startup | keepout filter enabled with no mask server | Either launch with `use_keepout:=true mask:=...`, or remove the `filters:` lines from **both** costmaps |
| A room is never cleaned | Doorway < **0.48 m** | `prepare_map.py` told you this in `home_qa.txt`. It physically will not fit |
| Motors get hot when idle | Working as designed for 10 s, then coils drop | `serial.idle_disable_ms` |
| Motors whine / lose steps on turns | Jerk limit too loose, or DIR flipping at speed | Raise `limits.jerk_time_s`; the signed-velocity design already prevents the latter |

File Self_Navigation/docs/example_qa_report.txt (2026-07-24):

MAP QA REPORT   2026-07-13 05:26
map                 : testmap/home.yaml
resolution          : 0.050 m/cell
robot radius        : 0.210 m  (diameter 0.420 m)
erosion radius      : 0.240 m
min passable gap    : 0.480 m
lane spacing        : 0.250 m

free floor area     : 48.91 m^2
reachable drivable  : 30.32 m^2
unreachable regions : 1
narrowest corridor  : 0.50 m

waypoints           : 5239  (527 edge + 4712 fill)
lanes               : 30
path length         : 312.4 m
ESTIMATED RUN       : 26 minutes

coverage (drivable) : 100.0%
floor swept (body)  : 80.8%

PROBLEMS:
  - unreachable 2.05 m^2 at (7.60, 1.15)

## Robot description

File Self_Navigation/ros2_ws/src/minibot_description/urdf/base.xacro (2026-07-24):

<?xml version="1.0"?>
<!-- ===========================================================================
     base.xacro : chassis, two driven wheels, two casters.   [REVISION 2]

     ##### REV 2: THE GEOMETRY CHANGED COMPLETELY #####
       wheel radius     0.190 -> 0.0336   (67.2 mm DIAMETER with rubber)
       wheel separation 0.300 -> 0.400    (centre-to-centre)
     Rev 1's numbers were wrong. Every velocity in the project derived from them.

     ##### THE WHEELS ARE THE WIDEST PART OF THE ROBOT #####
       body   = 38 cm across
       wheels = 42 cm across   <— WIDER
     Nav2 gets robot_radius = 0.210 (the WHEELS), not 0.190 (the body). Plan
     against the body and Nav2 will confidently drive the WHEELS into walls it
     believes it clears. That single number is the difference between a robot
     that hugs walls cleanly and one that grinds its tyres along them.

     WHY CIRCULAR STILL MATTERS
       For a disc, inscribed radius == circumscribed radius. The robot can rotate
       in place ANYWHERE it can stand — so every point on the coverage path is
       automatically a valid turning point. That is why coverage planning here is
       tractable at all, and why Nav2 gets a scalar radius instead of a polygon.

     FRAME CONVENTION
       base_link      = midpoint of the wheel AXLE = the CENTRE OF ROTATION.
                        It sits 0.0336 m (= wheel_radius) above the ground.
       base_footprint = base_link projected onto the floor.

     !! ALL GEOMETRY COMES FROM robot.yaml. If you change it there, change it
        HERE too (xacro cannot read yaml), or run tools/generate_config.py and
        copy from docs/DERIVED_NUMBERS.md.
=========================================================================== -->
<robot xmlns:xacro="http://www.ros.org/wiki/xacro">

  <!-- ============ MUST MATCH robot.yaml ============ -->
  <xacro:property name="wheel_radius" value="0.0336"/>   <!-- 67.2 mm dia -->
  <xacro:property name="wheel_separation" value="0.400"/>    <!-- centre-to-centre -->
  <xacro:property name="body_radius" value="0.190"/>    <!-- the chassis disc -->
  <!-- =============================================== -->

  <xacro:property name="body_height" value="0.090"/>
  <xacro:property name="body_mass" value="5.400"/>   <!-- 6 kg total - wheels/casters -->
  <xacro:property name="wheel_thickness" value="0.026"/>
  <xacro:property name="wheel_mass" value="0.250"/>
  <xacro:property name="wheel_offset_y" value="${wheel_separation/2}"/>
  <xacro:property name="caster_radius" value="0.0168"/>  <!-- HALF wheel_radius -->
  <xacro:property name="caster_offset_x" value="0.150"/>

  <material name="black"><color rgba="0.1 0.1 0.1 1"/></material>
  <material name="orange"><color rgba="1 0.35 0 1"/></material>
  <material name="white"><color rgba="1 1 1 1"/></material>
  <material name="cyan"><color rgba="0 0.8 0.9 1"/></material>
  <material name="green"><color rgba="0.2 0.8 0.2 1"/></material>

  <link name="base_link"/>

  <!-- base_link is at the wheel AXLE, so the floor is wheel_radius BELOW it. -->
  <joint name="base_footprint_joint" type="fixed">
    <parent link="base_link"/>
    <child link="base_footprint"/>
    <origin xyz="0 0 ${-wheel_radius}" rpy="0 0 0"/>
  </joint>
  <link name="base_footprint"/>

  <joint name="body_joint" type="fixed">
    <parent link="base_link"/>
    <child link="body"/>
    <!-- The 90 mm body disc sits ABOVE the little wheels, not centred on the
         axle. Its centre is half its height above base_link. -->
    <origin xyz="0 0 ${body_height/2}" rpy="0 0 0"/>
  </joint>
  <link name="body">
    <visual>
      <geometry><cylinder radius="${body_radius}" length="${body_height}"/></geometry>
      <material name="black"/>
    </visual>
    <collision>
      <geometry><cylinder radius="${body_radius}" length="${body_height}"/></geometry>
    </collision>
    <xacro:inertial_cylinder mass="${body_mass}" radius="${body_radius}" length="${body_height}">
      <origin xyz="0 0 0" rpy="0 0 0"/>
    </xacro:inertial_cylinder>
  </link>

  <joint name="left_wheel_joint" type="continuous">
    <parent link="base_link"/>
    <child link="left_wheel"/>
    <origin xyz="0 ${wheel_offset_y} 0" rpy="${-pi/2} 0 0"/>
    <axis xyz="0 0 1"/>
  </joint>
  <link name="left_wheel">
    <visual>
      <geometry><cylinder radius="${wheel_radius}" length="${wheel_thickness}"/></geometry>
      <material name="orange"/>
    </visual>
    <collision><geometry><sphere radius="${wheel_radius}"/></geometry></collision>
    <xacro:inertial_cylinder mass="${wheel_mass}" radius="${wheel_radius}" length="${wheel_thickness}">
      <origin xyz="0 0 0" rpy="0 0 0"/>
    </xacro:inertial_cylinder>
  </link>

  <joint name="right_wheel_joint" type="continuous">
    <parent link="base_link"/>
    <child link="right_wheel"/>
    <origin xyz="0 ${-wheel_offset_y} 0" rpy="${pi/2} 0 0"/>
    <axis xyz="0 0 -1"/>
  </joint>
  <link name="right_wheel">
    <visual>
      <geometry><cylinder radius="${wheel_radius}" length="${wheel_thickness}"/></geometry>
      <material name="orange"/>
    </visual>
    <collision><geometry><sphere radius="${wheel_radius}"/></geometry></collision>
    <xacro:inertial_cylinder mass="${wheel_mass}" radius="${wheel_radius}" length="${wheel_thickness}">
      <origin xyz="0 0 0" rpy="0 0 0"/>
    </xacro:inertial_cylinder>
  </link>

  <!-- Casters are HALF the wheel radius, so their centres sit at
       (-wheel_radius + caster_radius) and their bottoms touch the floor. -->
  <xacro:macro name="caster" params="name x">
    <joint name="${name}_joint" type="fixed">
      <parent link="base_link"/>
      <child link="${name}"/>
      <origin xyz="${x} 0 ${-wheel_radius + caster_radius}"/>
    </joint>
    <link name="${name}">
      <visual><geometry><sphere radius="${caster_radius}"/></geometry><material name="white"/></visual>
      <collision><geometry><sphere radius="${caster_radius}"/></geometry></collision>
      <xacro:inertial_sphere mass="0.03" radius="${caster_radius}">
        <origin xyz="0 0 0" rpy="0 0 0"/>
      </xacro:inertial_sphere>
    </link>
  </xacro:macro>

  <xacro:caster name="caster_front" x="${caster_offset_x}"/>
  <xacro:caster name="caster_rear" x="${-caster_offset_x}"/>

  <!-- ======================= CLEANING BRUSHES ==========================
       Two brushes, 100 mm diameter, centres 200 mm apart. VISUAL ONLY — but
       they are in the URDF so you can SEE in RViz exactly what the robot does
       and does not sweep.

           left  brush covers  -0.150 .. -0.050
           right brush covers  +0.050 .. +0.150
           TOTAL SWEPT WIDTH   0.300 m
           GAP IN THE MIDDLE   0.100 m   <— your suction inlet had better be here

       Mounted at the FRONT of the body.
  =================================================================== -->
  <xacro:property name="brush_radius" value="0.050"/>
  <xacro:property name="brush_separation" value="0.200"/>
  <xacro:property name="brush_offset_x" value="0.120"/>

  <xacro:macro name="brush" params="name y">
    <joint name="${name}_joint" type="fixed">
      <parent link="base_link"/>
      <child link="${name}"/>
      <origin xyz="${brush_offset_x} ${y} ${-wheel_radius + 0.008}"/>
    </joint>
    <link name="${name}">
      <visual>
        <geometry><cylinder radius="${brush_radius}" length="0.015"/></geometry>
        <material name="green"/>
      </visual>
    </link>
  </xacro:macro>

  <xacro:brush name="brush_left" y="${ brush_separation/2}"/>
  <xacro:brush name="brush_right" y="${-brush_separation/2}"/>

</robot>

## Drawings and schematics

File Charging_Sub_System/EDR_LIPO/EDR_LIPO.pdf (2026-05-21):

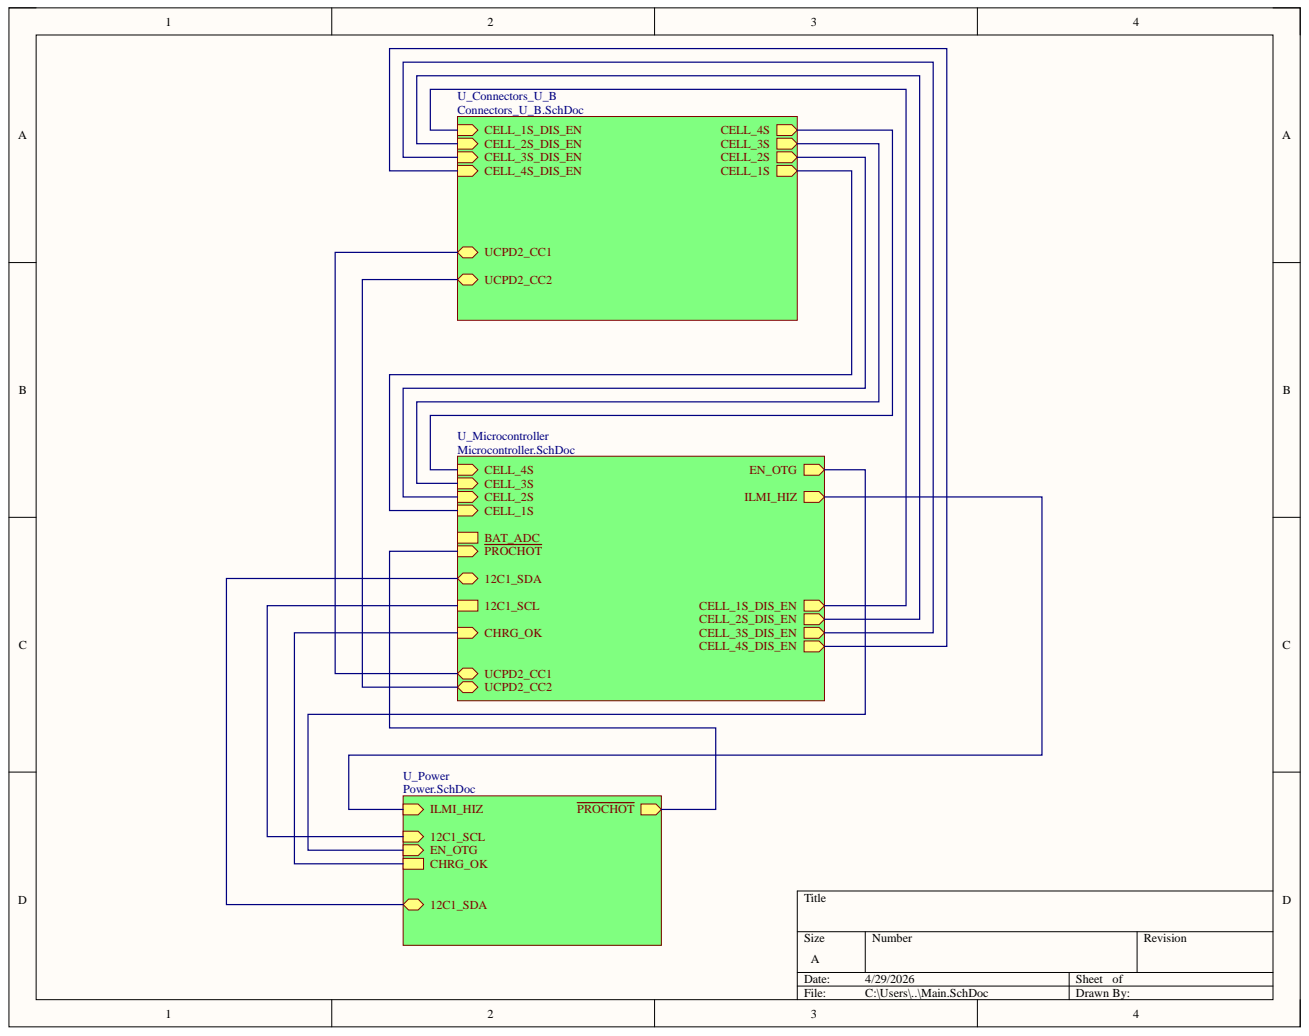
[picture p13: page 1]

U_Power Power.SchDoc

12C1_SCL
EN_OTG

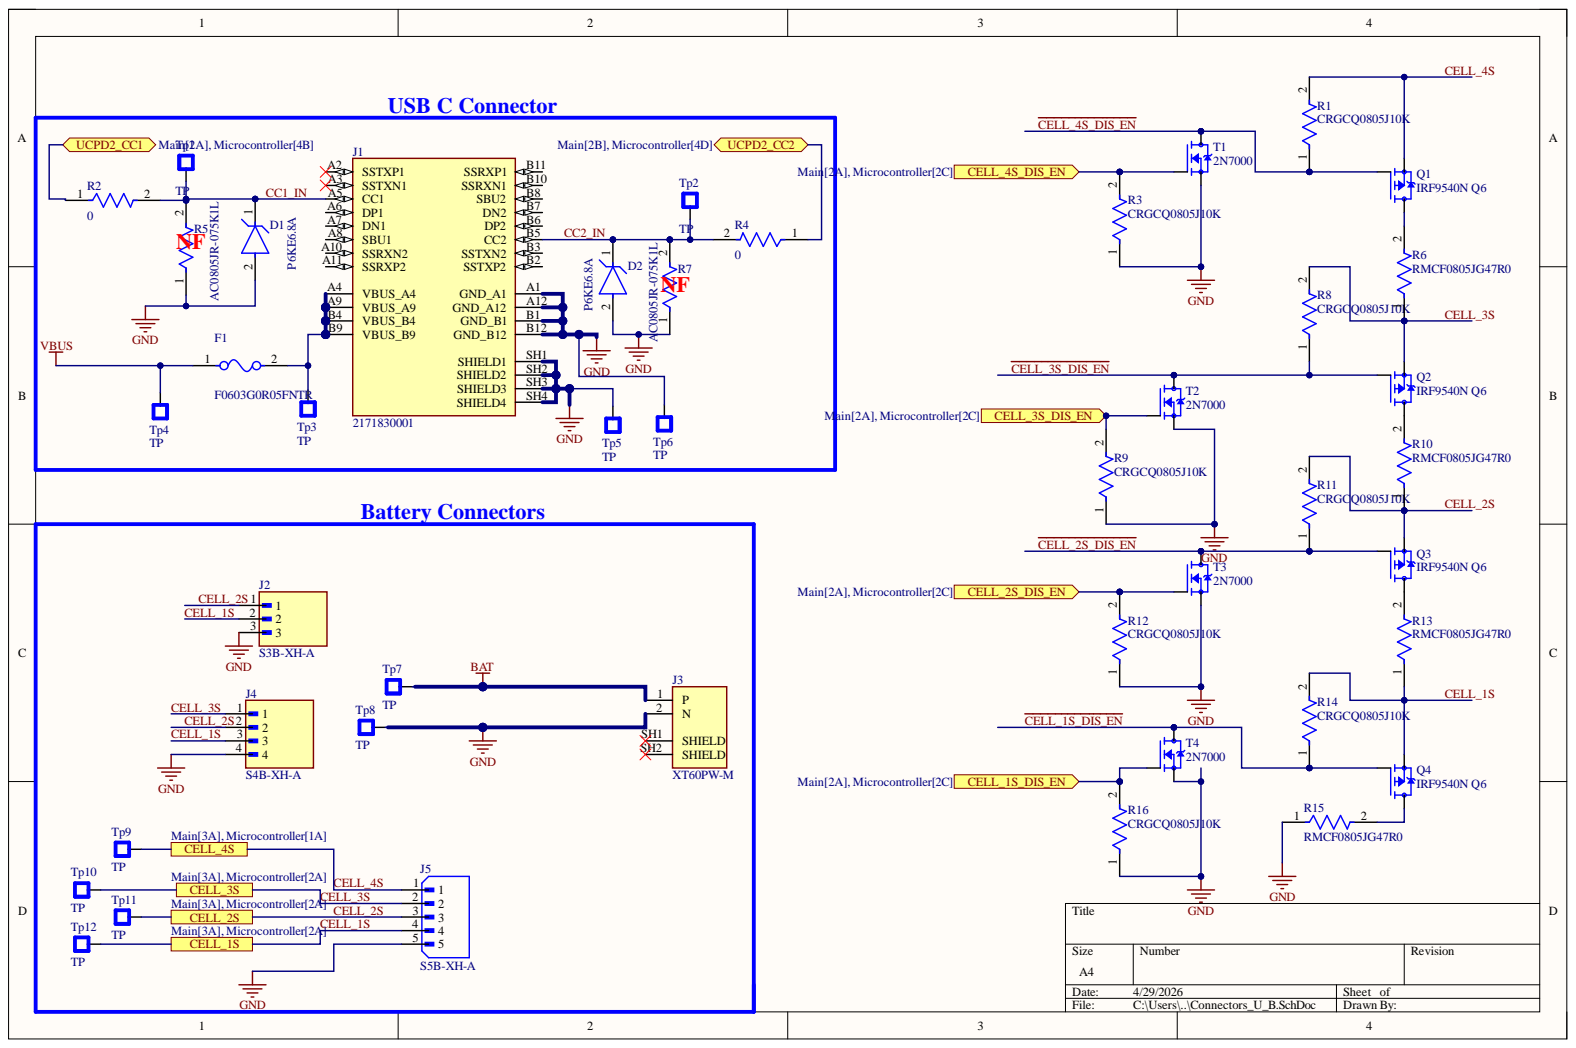
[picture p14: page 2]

B 4 | B 1
B 9 | B12

S H | 3
S H | 4

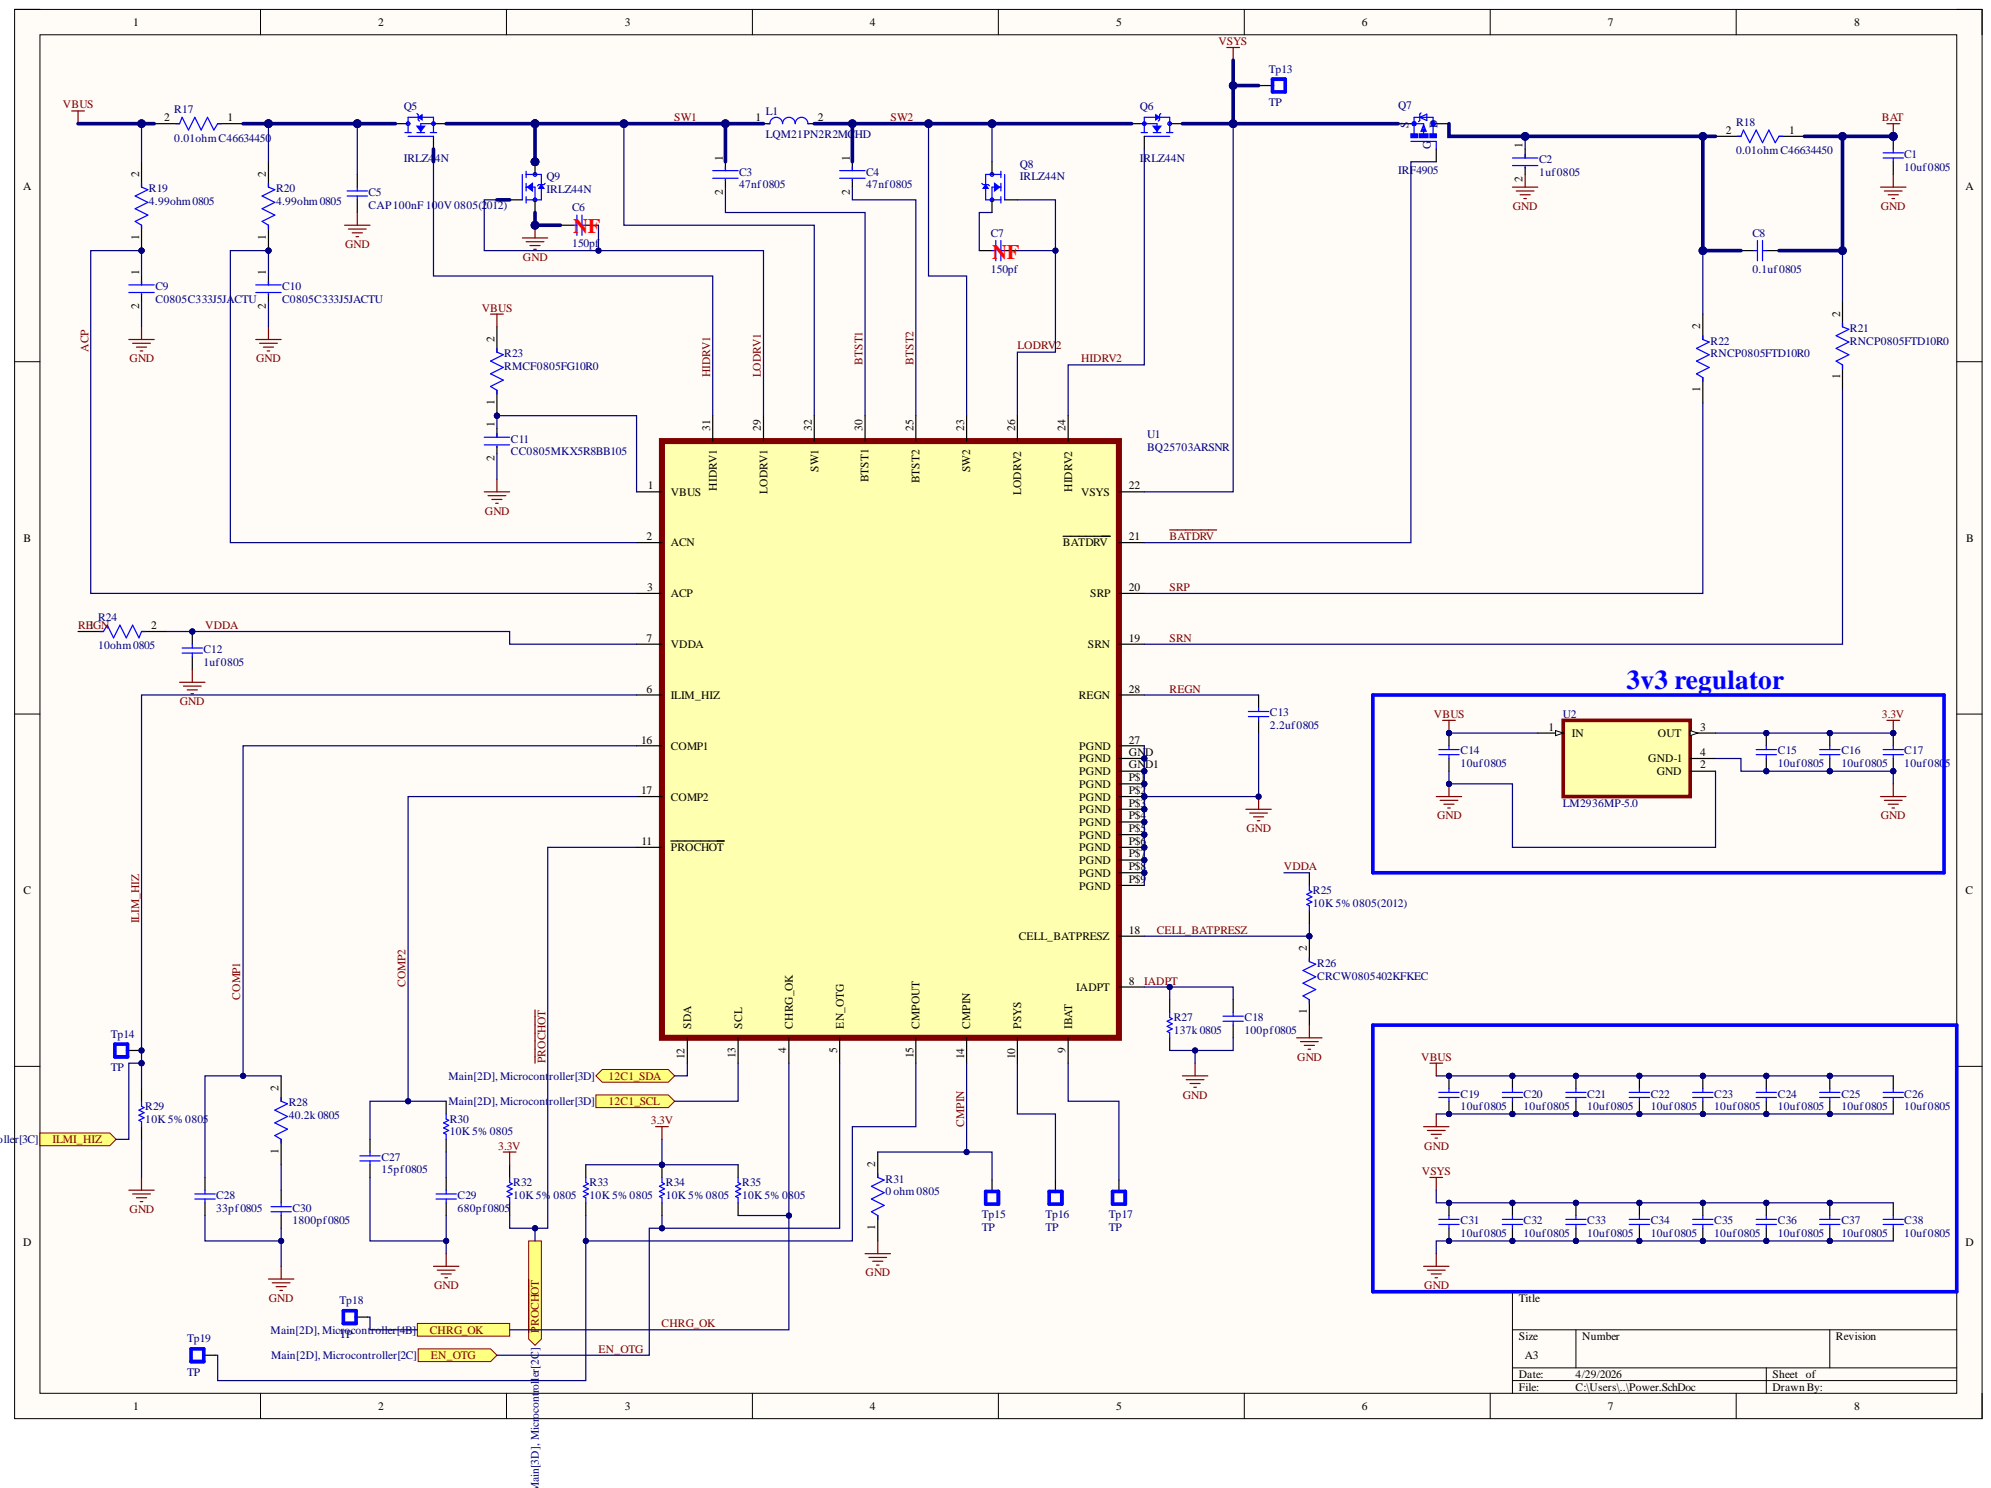
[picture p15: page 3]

C11 CC0805MKX5R8BB105

U1 BQ25703ARSNR

ACN 2 | BATDRV

ACP 3 | SRP

VDDA 7 | SRN

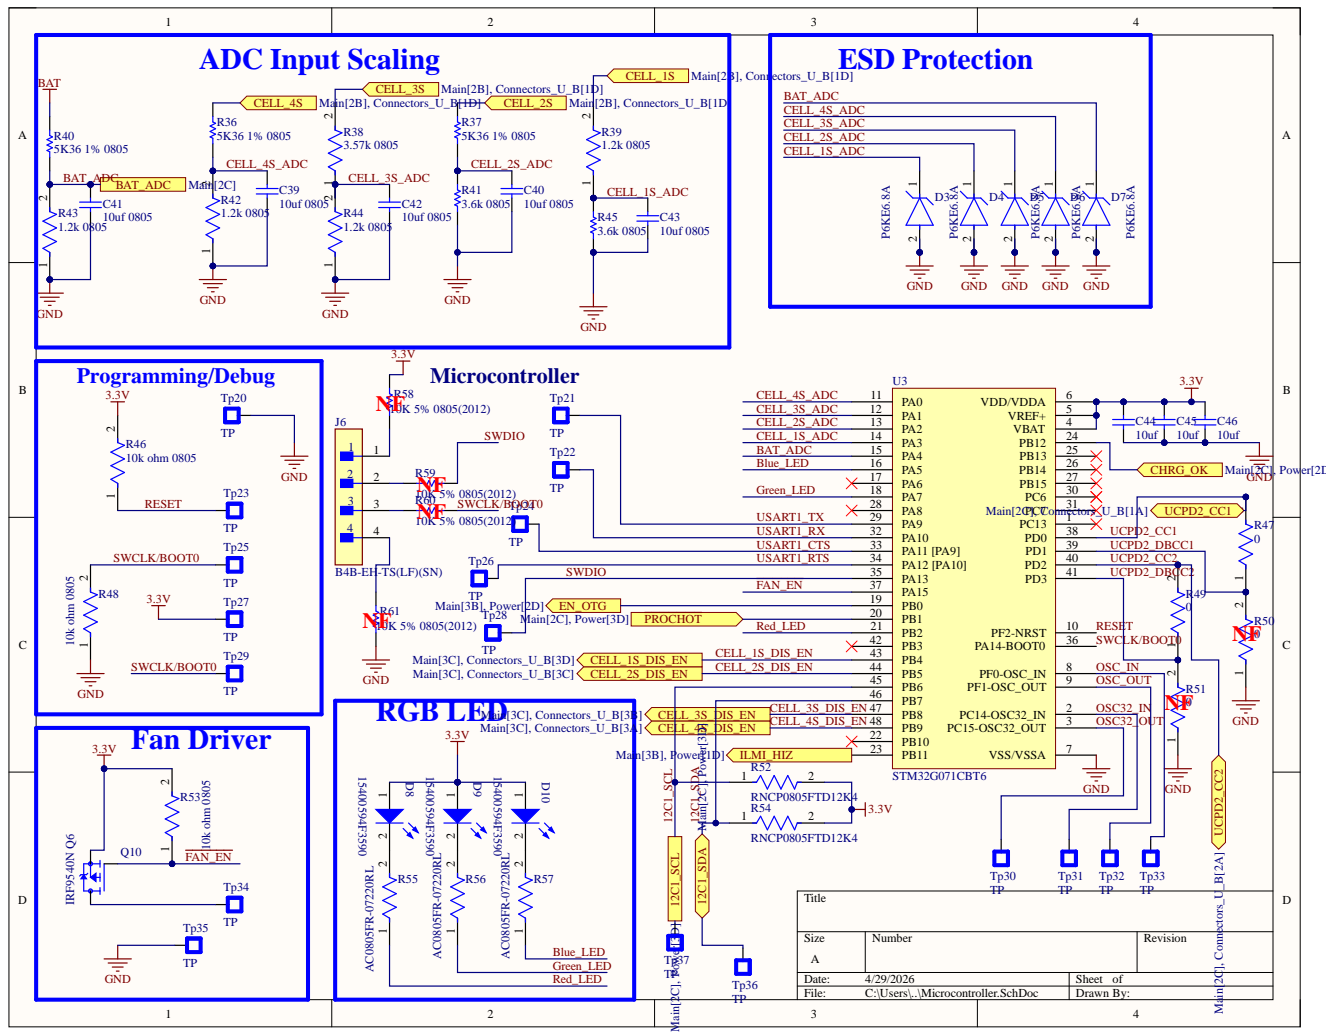
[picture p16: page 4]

PB6 45 | OSC_OUT
PB7 46 | OSC32_IN

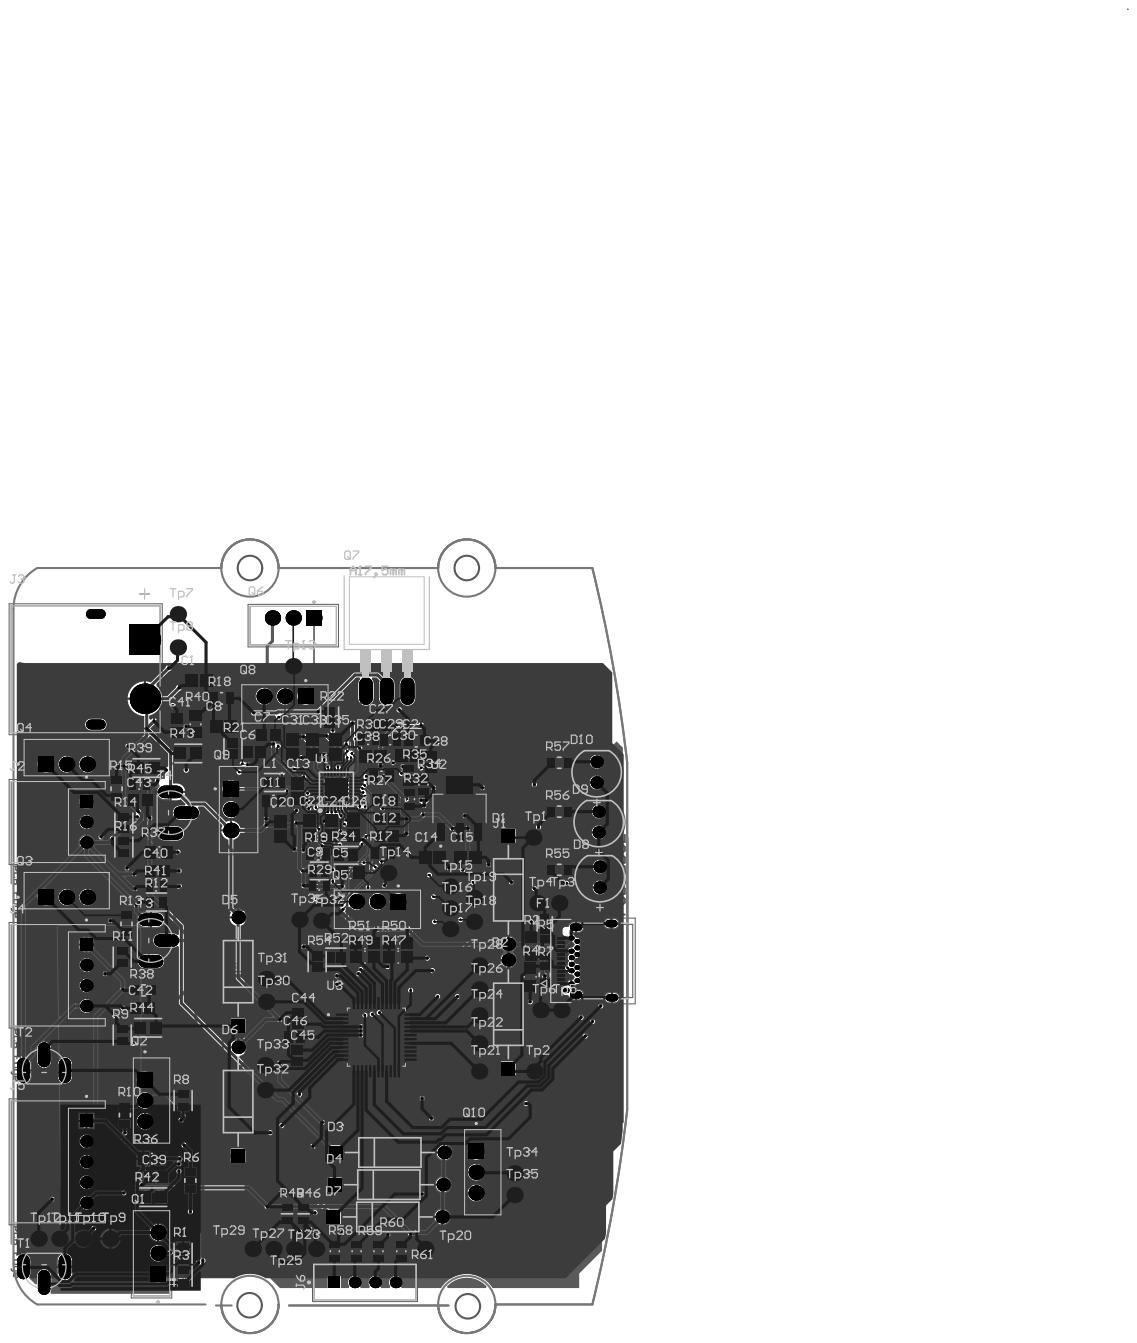
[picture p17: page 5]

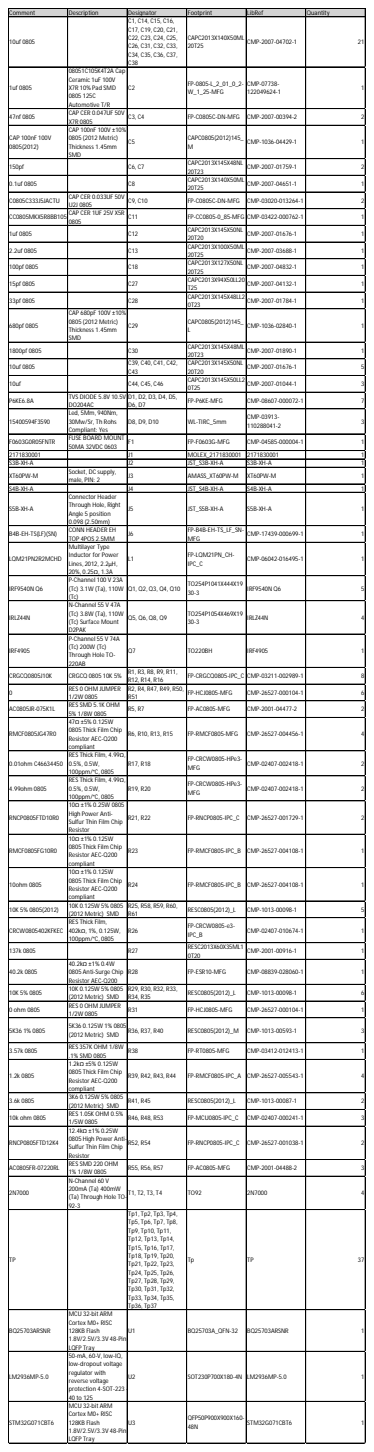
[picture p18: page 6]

1uf 0805 | 08051C105K4T2A Cap Ceramic 1uF 100V X7R 10% Pad SMD 0805 125C Automotive T/R | C2 | FP-0805-L_2_01_0_2-W_1_25-MFG | CMP-07738-122049624-1 | | 1

47nf 0805 | CAP CER 0.047UF 50V X7R 0805 | C3, C4 | FP-C0805C-DN-MFG | CMP-2007-00394-2 | | 2

CAP 100nF 100V 0805(2012) | CAP 100nF 100V ±10% 0805 (2012 Metric) Thickness 1.45mm SMD | C5 | CAPC0805(2012)145_ M | CMP-1036-04429-1 | | 1

150pf | | C6, C7 | CAPC2013X145X48NL 20T23 | CMP-2007-01759-1 | | 2

0.1uf 0805 | | C8 | CAPC2013X140X50ML 20T25 | CMP-2007-04651-1 | | 1

C0805C333J5JACTU | CAP CER 0.033UF 50V U2J 0805 | C9, C10 | FP-C0805C-DN-MFG | CMP-03020-013264-1 | | 2

CC0805MKX5R8BB105 CAP CER 1UF 25V X5R | 0805 | C11 | FP-CC0805-0_85-MFG | CMP-03422-000762-1 | | 1

1uf 0805 | | C12 | CAPC2013X145X50NL 20T20 | CMP-2007-01676-1 | | 1

2.2uf 0805 | | C13 | CAPC2013X100X50ML 20T25 | CMP-2007-03688-1 | | 1

100pf 0805 | | C18 | CAPC2013X127X50NL 20T25 | CMP-2007-04832-1 | | 1

15pf 0805 | | C27 | CAPC2013X94X50LL20 T25 | CMP-2007-04132-1 | | 1

33pf 0805 | | C28 | CAPC2013X145X48LL2 0T23 | CMP-2007-01784-1 | | 1

680pf 0805 | CAP 680pF 100V ±10% 0805 (2012 Metric) Thickness 1.45mm SMD | C29 | CAPC0805(2012)145_ L | CMP-1036-02840-1 | | 1

1800pf 0805 | | C30 | CAPC2013X145X48ML 20T23 | CMP-2007-01890-1 | | 1

10uf 0805 | | C39, C40, C41, C42, C43 | CAPC2013X145X50NL 20T20 | CMP-2007-01676-1 | | 5

10uf | | C44, C45, C46 | CAPC2013X145X50LL2 0T25 | CMP-2007-01044-1 | | 3

P6KE6.8A | TVS DIODE 5.8V 10.5V DO204AC | D1, D2, D3, D4, D5, D6, D7 | FP-P6KE-MFG | CMP-08607-000072-1 | | 7

15400594F3590 | Led, 5Mm, 940Nm, 30Mw/Sr, Th Rohs Compliant: Yes | D8, D9, D10 | WL-TIRC_5mm | CMP-03913-110288041-2 | | 3

F0603G0R05FNTR | FUSE BOARD MOUNT 50MA 32VDC 0603 | F1 | FP-F0603G-MFG | CMP-04585-000004-1 | | 1

2171830001 | | J1 | MOLEX_2171830001 | 2171830001 | | 1
S3B-XH-A | | J2 | JST_S3B-XH-A | S3B-XH-A | | 1
XT60PW-M | Socket, DC supply, male, PIN: 2 | J3 | AMASS_XT60PW-M | XT60PW-M | | 1

S4B-XH-A | | J4 | JST_S4B-XH-A | S4B-XH-A | | 1
S5B-XH-A | Connector Header Through Hole, Right Angle 5 position 0.098 (2.50mm) | J5 | JST_S5B-XH-A | S5B-XH-A | | 1

B4B-EH-TS(LF)(SN) | CONN HEADER EH TOP 4POS 2.5MM | J6 | FP-B4B-EH-TS_LF_SN-MFG | CMP-17439-000699-1 | | 1

LQM21PN2R2MCHD | Multilayer Type Inductor for Power Lines, 2012, 2.2μH, 20%, 0.25Ω, 1.3A | L1 | FP-LQM21PN_CH-IPC_C | CMP-06042-016495-1 | | 1

IRF9540N Q6 | P-Channel 100 V 23A (Tc) 3.1W (Ta), 110W (Tc) | Q1, Q2, Q3, Q4, Q10 | TO254P1041X444X19 30-3 | IRF9540N Q6 | | 5

IRLZ44N | N-Channel 55 V 47A (Tc) 3.8W (Ta), 110W (Tc) Surface Mount D2PAK | Q5, Q6, Q8, Q9 | TO254P1054X469X19 30-3 | IRLZ44N | | 4

IRF4905 | P-Channel 55 V 74A (Tc) 200W (Tc) Through Hole TO-220AB | Q7 | TO220BH | IRF4905 | | 1

CRGCQ0805J10K | CRGCQ 0805 10K 5% | R1, R3, R8, R9, R11, R12, R14, R16 | FP-CRGCQ0805-IPC_C CMP-03211-002989-1 | | | 8

0 | RES 0 OHM JUMPER 1/2W 0805 | R2, R4, R47, R49, R50, R51 | FP-HCJ0805-MFG | CMP-26527-000104-1 | | 6

AC0805JR-075K1L | RES SMD 5.1K OHM 5% 1/8W 0805 | R5, R7 | FP-AC0805-MFG | CMP-2001-04477-2 | | 2

RMCF0805JG47R0 | 47Ω ±5% 0.125W 0805 Thick Film Chip Resistor AEC-Q200 compliant | R6, R10, R13, R15 | FP-RMCF0805-MFG | CMP-26527-004456-1 | | 4

0.01ohm C46634450 | RES Thick Film, 4.99Ω, 0.5%, 0.5W, 100ppm/°C, 0805 | R17, R18 | FP-CRCW0805-HPe3-MFG | CMP-02407-002418-1 | | 2

4.99ohm 0805 | RES Thick Film, 4.99Ω, 0.5%, 0.5W, 100ppm/°C, 0805 | R19, R20 | FP-CRCW0805-HPe3-MFG | CMP-02407-002418-1 | | 2

RNCP0805FTD10R0 | 10Ω ±1% 0.25W 0805 High Power Anti-Sulfur Thin Film Chip Resistor | R21, R22 | FP-RNCP0805-IPC_C | CMP-26527-001729-1 | | 2

RMCF0805FG10R0 | 10Ω ±1% 0.125W 0805 Thick Film Chip Resistor AEC-Q200 compliant | R23 | FP-RMCF0805-IPC_B | CMP-26527-004108-1 | | 1

10ohm 0805 | 10Ω ±1% 0.125W 0805 Thick Film Chip Resistor AEC-Q200 compliant | R24 | FP-RMCF0805-IPC_B | CMP-26527-004108-1 | | 1

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

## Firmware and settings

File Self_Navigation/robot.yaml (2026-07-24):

# =============================================================================
#  robot.yaml -- THE SINGLE SOURCE OF TRUTH.   [REVISION 2 -- MEASURED HARDWARE]
#
#      python3 tools/generate_config.py
#
#  NEVER hand-edit a generated file. These numbers live in five places (STM32
#  firmware, ros2_control, Nav2 controller_server, Nav2 velocity_smoother, the
#  coverage planner). If any two disagree the strictest layer SILENTLY CLIPS the
#  others -- and the planner then believes the robot went somewhere it did not.
#
#  ###########################################################################
#  #  WHAT CHANGED IN REVISION 2, AND WHY IT MATTERS                         #
#  #                                                                          #
#  #  Rev 1 used wheel_radius 0.19 m and wheel_separation 0.30 m. BOTH WRONG. #
#  #  Measured:                                                               #
#  #      wheel   67.2 mm DIAMETER (with rubber)  -> radius 0.0336 m          #
#  #      wheels  40 cm CENTRE-TO-CENTRE          -> separation 0.400 m       #
#  #      wheels  41-42 cm OUTER SPAN             -> robot_radius 0.210 m     #
#  #      lidar   25 cm above the GROUND                                      #
#  #                                                                          #
#  #  Rev 1 argued "5-20 RPM only makes sense with BIG wheels". The wheels are #
#  #  small. So the correct conclusion was the OPPOSITE: the 20 RPM cap is the #
#  #  suspect number, not the wheel size. See limits.max_wheel_rpm.            #
#  ###########################################################################
# =============================================================================

geometry:
  # --- MEASURED. Do not change without re-measuring. -----------------------
  wheel_radius: 0.0336         # m. 67.2 mm DIAMETER with rubber.
                               # MEASURE IT LOADED (robot weight on the wheel).
                               # Rubber compresses ~1 mm under load; measuring
                               # it unloaded is a silent 3% odometry error.
  wheel_separation: 0.400      # m. CENTRE-to-CENTRE of the contact patches.
                               # (Outer ends 41-42 cm; midpoints 40 cm. The
                               # kinematics needs the MIDPOINT number.)

  # !! THE WHEELS ARE THE WIDEST PART OF THE ROBOT !!
  # Body is 380 mm across; wheels span 410-420 mm. Nav2 MUST plan against the
  # widest extent or it will drive the WHEELS into walls it believes it clears.
  robot_radius: 0.210          # m. HALF the 420 mm wheel span. NOT half the body.
  body_radius: 0.190           # m. The chassis disc. Visual only.

  # Height from the GROUND to the LIDAR scan plane. generate_config.py converts
  # this into a base_link-relative z (base_link sits at the wheel axle, which is
  # wheel_radius above the ground).
  lidar_height_from_ground: 0.250
  imu_height_from_ground: 0.060      # <-- I AM GUESSING. MEASURE IT.

  # --- Drivetrain ----------------------------------------------------------
  motor_steps_per_rev: 200     # 1.8 deg/step NEMA17. 400 if yours is 0.9 deg.
                               # VERIFY: stm32_bench.py --verify-steps
  microstepping: 16            # DRV8825 jumpers: M0=LOW  M1=LOW  M2=HIGH
  gear_ratio: 1.0              # motor turns per WHEEL turn. Direct drive = 1.0

mass:
  robot_kg: 6.0
  motor_holding_torque_nm: 0.40   # <-- UNVERIFIED. Typical NEMA17 42-34 @ 1.4 A.
                                  # I do NOT have your motor's datasheet. Read the
                                  # real number off the motor label before trusting
                                  # the torque margin below.
  rolling_resistance_coeff: 0.02  # hard floor. Carpet is 0.05-0.15.

limits:
  # ###########################################################################
  #  THE 20 RPM CAP IS NOW THE SINGLE BIGGEST COST IN THE PROJECT.
  #
  #  With your REAL 33.6 mm wheels:
  #     RPM    speed       step rate   % of pulse engine   49 m^2 flat
  #      20   0.070 m/s     1066 sps        5.3%             ~95 min
  #      40   0.141 m/s     2133 sps       10.7%             ~47 min
  #      60   0.211 m/s     3200 sps       16.0%             ~31 min
  #     100   0.352 m/s     5333 sps       26.7%             ~19 min
  #
  #  At 20 RPM the pulse engine is 5% used and the motors have ~12x torque margin
  #  at 6 kg. The cap buys you nothing and costs you an hour per run.
  #
  #  LEFT AT 20 because that is what you specified and you have not said
  #  otherwise. If it was a guess, change ONE NUMBER here, re-run
  #  generate_config.py, and the entire stack retunes itself.
  # ###########################################################################
  max_wheel_rpm: 20.0
  min_wheel_rpm: 5.0

  accel_time_s: 0.50     # standstill -> max speed
  jerk_time_s: 0.15      # 0 -> max acceleration. Rounds the S-curve corners.
                         # NOT a nicety: the robot reverses direction at the end
                         # of every lane (~34x per room) and a torque STEP is
                         # exactly the impulse that makes a stepper skip.

coverage:
  # --- YOUR REAL CLEANING HEAD ---------------------------------------------
  #  Two brushes, 100 mm diameter, centres 200 mm apart:
  #      left  brush covers -0.150 .. -0.050
  #      right brush covers +0.050 .. +0.150
  #      TOTAL SWEPT WIDTH = 0.300 m
  #      GAP IN THE MIDDLE = 0.100 m
  #
  #  !!! CONFIRM THIS !!!  The 100 mm middle gap is fine ONLY IF your suction
  #  inlet sits there (side brushes sweeping debris inward is the standard
  #  design). If there is nothing in the middle, you have a 100 mm uncleaned
  #  stripe down the centre of EVERY lane, and no path planner can fix it.
  brush_diameter: 0.10
  brush_separation: 0.20
  cleaning_head_width: 0.30    # = brush_separation + brush_diameter

  # Your spec said 0.19 m lanes. Against a 0.30 m head that is 11 cm of overlap
  # on every pass -- 37% of the floor cleaned twice. 0.25 m still leaves 5 cm of
  # overlap and cuts run time ~25%. KEPT AT 0.19 because you specified 0.19.
  lane_spacing: 0.19

  safety_margin: 0.03    # clearance beyond robot_radius.
                         # Drop to 0.01 and the uncleaned wall strip shrinks
                         # from 9 cm to 7 cm, at the cost of wall clearance.
  waypoint_spacing: 0.15
  min_segment_length: 0.25
  min_region_area: 0.60
  do_edge_pass: true     # THIS is what cleans the corners. Do not disable.

serial:
  device: /dev/ttyAMA0   # Pi 5 GPIO UART: PA9/PA10 <-> GPIO14/15, needs dtoverlay=uart0-pi5
  baud_rate: 115200
  feedback_hz: 50
  cmd_timeout_ms: 500    # no command -> ramp to stop, STAY energised (holding
                         # torque; the robot must not roll away on a slope)
  idle_disable_ms: 10000 # long idle -> drop the coils. A stationary stepper at
                         # full current is a 10 W heater doing no work.

firmware:
  isr_hz: 40000          # TIM7 step-engine tick
  ramp_hz: 1000          # motion-profile update rate
  left_dir_invert: 1     # robot spins instead of driving? flip exactly ONE
  right_dir_invert: 0    # robot drives backwards?         flip BOTH

sensors:
  lidar_device: /dev/minibot_lidar
  lidar_max_range: 12.0
  lidar_min_range: 0.15
  imu_i2c_bus: 1
  imu_i2c_address: 0x68
  imu_rate_hz: 100
  # Chip flat, silkscreen up, +X arrow forward -> ['x','y','z']
  # Upside down                                -> ['x','-y','-z']
  # DETERMINE IT: ros2 run minibot_imu imu_calibrate.py --axis-check
  imu_axis_map: ['x', '-y', '-z']

dock:
  x: 0.0
  y: 0.0
  yaw: 0.0
  frame: map

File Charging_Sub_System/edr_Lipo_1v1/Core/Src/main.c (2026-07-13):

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

/* Includes ------------------------------------------------------------------*/
#include "main.h"
#include "cmsis_os.h"
#include "usbpd.h"

/* USER CODE BEGIN Includes */

// Application level
#include "UARTCommandConsole.h"
#include "adc_interface.h"
#include "battery.h"
#include "bq25703a_regulator.h"
#include "gui_api.h"

// System
#include "printf.h"
#include "stm32g0xx_hal_flash.h"
#include "stm32g0xx_hal_flash_ex.h"
#include "stm32g0xx_hal_tim.h"
#include "error.h"

/* USER CODE END Includes */

/* USER CODE BEGIN PD */

/* Format of the different kind of message */
/*   - 31-28  4 bit for the message type   */
#define DEMO_MSG_TYPE_POS                 28u
#define DEMO_MSG_TYPE_MSK                 (0xFu << DEMO_MSG_TYPE_POS)
#define DEMO_MSG_MMI                      (0u   << DEMO_MSG_TYPE_POS)
#define DEMO_MSG_CAD                      (1u   << DEMO_MSG_TYPE_POS)
#define DEMO_MSG_PENOTIFY                 (2u   << DEMO_MSG_TYPE_POS)

/* USER CODE END PD */

/* NOTE: these handles are actually defined (owned) in adc.c / i2c.c / tim.c /
 * usart.c respectively. They used to be redefined here too, which caused
 * "multiple definition" linker errors -- declared extern here instead. */
extern ADC_HandleTypeDef hadc1;
extern DMA_HandleTypeDef hdma_adc1;

extern I2C_HandleTypeDef hi2c1;
extern DMA_HandleTypeDef hdma_i2c1_tx;
extern DMA_HandleTypeDef hdma_i2c1_rx;

extern TIM_HandleTypeDef htim7;

extern UART_HandleTypeDef huart1;
extern DMA_HandleTypeDef hdma_usart1_tx;
extern DMA_HandleTypeDef hdma_usart1_rx;

osThreadId defaultTaskHandle;
/* USER CODE BEGIN PV */

osThreadId blinkyTaskHandle;

SemaphoreHandle_t xTxMutex_CLI;
SemaphoreHandle_t xTxMutex_Regulator;

/* USER CODE END PV */

void SystemClock_Config(void);
static void MX_GPIO_Init(void);
static void MX_DMA_Init(void);
static void MX_ADC1_Init(void);
static void MX_I2C1_Init(void);
static void MX_TIM7_Init(void);
static void MX_USART1_UART_Init(void);
static void MX_UCPD2_Init(void);
void StartDefaultTask(void const * argument);

/* USER CODE BEGIN PFP */

void vLED_Blinky(void const *pvParameters);

/* USER CODE END PFP */

/* USER CODE BEGIN 0 */
const uint8_t HWBoardVersionName[] = "TBD";
const uint8_t PDTypeName[] = "TBD";
const uint8_t* BSP_GetHWBoardVersionName(void);
const uint8_t* BSP_GetPDTypeName(void);
const uint8_t* BSP_GetHWBoardVersionName(void)
{
  return HWBoardVersionName;
}

const uint8_t* BSP_GetPDTypeName(void)
{
  return PDTypeName;
}

/* USER CODE END 0 */

/**
  * @brief  The application entry point.
  * @retval int
  */
int main(void)
{
  /* MCU Configuration--------------------------------------------------------*/

  /* Reset of all peripherals, Initializes the Flash interface and the Systick. */
  HAL_Init();

  /* Configure the system clock */
  SystemClock_Config();

  /* Initialize all configured peripherals */
  MX_GPIO_Init();
  MX_DMA_Init();
  MX_ADC1_Init();
  MX_I2C1_Init();
  MX_TIM7_Init();
  MX_UCPD2_Init();
  /* USER CODE BEGIN 2 */

  // Check nBOOT_SEL value. Set if not 0. Enables BOOT mode from BOOT0 Pin
  FLASH_OBProgramInitTypeDef OBInit; // programming option structure
  HAL_FLASHEx_OBGetConfig(&OBInit);
  if ((OBInit.USERConfig & OB_USER_nBOOT_SEL) == OB_BOOT0_FROM_OB) {
    // unlock flash
    if(HAL_FLASH_Unlock() == HAL_OK) {
      // unlock option bytes in particular
      if(HAL_FLASH_OB_Unlock() == HAL_OK) {
        // program selected option byte
        OBInit.OptionType = OPTIONBYTE_USER;
        OBInit.USERType = OB_USER_nBOOT_SEL;
        OBInit.USERConfig = 0;
        HAL_FLASHEx_OBProgram(&OBInit); // result not checked as there is no recourse at this point
        if(HAL_FLASH_OB_Lock() == HAL_OK) {
            HAL_FLASH_Lock(); // again, no recourse
            HAL_FLASH_OB_Launch(); // reset occurs here (sorry, debugger)
        }
      }
    }
  }

#if defined(_GUI_INTERFACE)
  /* Disable dead battery to use USART1_RX used by GUI 	*/
  LL_APB2_GRP1_EnableClock(LL_APB2_GRP1_PERIPH_SYSCFG);
  LL_SYSCFG_DisableDBATT(SYSCFG_CFGR1_UCPD2_STROBE);
  /* Initialize GUI */
  GUI_Init(BSP_GetHWBoardVersionName, BSP_GetPDTypeName);
#endif /* _GUI_INTERFACE */
  /* USER CODE END 2 */
  /* USBPD initialisation ---------------------------------*/
  MX_USBPD_Init();

  /* USER CODE BEGIN RTOS_MUTEX */
	xTxMutex_Regulator = xSemaphoreCreateMutex();
	configASSERT(xTxMutex_Regulator);

	xTxMutex_CLI = xSemaphoreCreateMutex();
	configASSERT(xTxMutex_CLI);
  /* USER CODE END RTOS_MUTEX */

  /* USER CODE BEGIN RTOS_SEMAPHORES */
	/* add semaphores, ... */
  /* USER CODE END RTOS_SEMAPHORES */

  /* USER CODE BEGIN RTOS_TIMERS */
	/* start timers, add new ones, ... */
  /* USER CODE END RTOS_TIMERS */

  /* USER CODE BEGIN RTOS_QUEUES */
	/* add queues, ... */
  /* USER CODE END RTOS_QUEUES */

  /* Create the thread(s) */
  /* definition and creation of defaultTask */
  osThreadDef(defaultTask, StartDefaultTask, osPriorityNormal, 0, 128);
  defaultTaskHandle = osThreadCreate(osThread(defaultTask), NULL);

  /* USER CODE BEGIN RTOS_THREADS */

	osThreadDef(blink_led, vLED_Blinky, LED_TASK_PRIORITY, 0, configMINIMAL_STACK_SIZE);
	blinkyTaskHandle = osThreadCreate(osThread(blink_led), NULL);

	/* Start the adc task */
	osThreadDef(read_adc, vRead_ADC, ADC_TASK_PRIORITY, 0, vRead_ADC_STACK_SIZE);
	adcTaskHandle = osThreadCreate(osThread(read_adc), NULL);

	/* Start the task that manages the regulator*/
	osThreadDef(regulator, vRegulator, REGULATOR_TASK_PRIORITY, 0, vRegulator_STACK_SIZE);
	regulatorTaskHandle = osThreadCreate(osThread(regulator), NULL);

#if defined(_CLI_INTERFACE)
	MX_USART1_UART_Init();
	/* Initialize CLI */
	/* Start the Command Line Interface on UART1 */
	osThreadDef(CLI, prvUARTCommandConsoleTask, UART_CLI_TASK_PRIORITY, 0, vcliSTACK_SIZE);
	CLITaskHandle = osThreadCreate(osThread(CLI), NULL);

	/* Register commands with the FreeRTOS+CLI command interpreter. */
	vRegisterCLICommands();
#endif /* _CLI_INTERFACE */

	/* Initialize the Device Policy Manager */
	if( USBPD_ERROR == USBPD_DPM_InitOS())
	{
		/* error the OS init  */
		while(1);
	}

  /* USER CODE END RTOS_THREADS */

  /* Start scheduler */
  osKernelStart();
  
  /* We should never get here as control is now taken by the scheduler */

  /* Infinite loop */
  /* USER CODE BEGIN WHILE */
	while (1) {
    /* USER CODE END WHILE */

    /* USER CODE BEGIN 3 */
	}
  /* USER CODE END 3 */
}

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
/* USER CODE BEGIN 4 */

/* ---------------------------------------------------------------------------
 * RGB status LED — active-LOW wiring on this board:
 *   GPIO_PIN_RESET (0) = colour ON, GPIO_PIN_SET (1) = colour OFF.
 * Colour = Red + Green mixed on a common-anode RGB (no blue used here):
 *   Red only   -> RED      (charging, pack low)
 *   Red+Green  -> YELLOW   (charging, pack medium)
 *   Green only -> GREEN    (charging, pack high / essentially full)
 * Behaviour requested:
 *   - Charging + low     -> RED
 *   - Charging + medium  -> YELLOW
 *   - Charging + high    -> GREEN
 *   - Error (any bit set)-> all three ON (white), then flash
 *   - Not charging / idle-> OFF
 * "Charging" here means the balance port is connected AND the regulator
 * reports it is actively charging. Level is decided from the highest cell
 * voltage so a nearly-full pack shows green even mid-balance.
 * ------------------------------------------------------------------------- */

/* Per-cell thresholds (volts * BATTERY_ADC_MULTIPLIER, = *1e6). */
#define LED_CELL_LOW_THRESH_UV   (uint32_t)( 3.6 * BATTERY_ADC_MULTIPLIER )  /* below -> LOW  (red)    */
#define LED_CELL_HIGH_THRESH_UV  (uint32_t)( 4.1 * BATTERY_ADC_MULTIPLIER )  /* at/above -> HIGH (green)*/

static inline void LED_Set(uint8_t red_on, uint8_t green_on, uint8_t blue_on) {
	/* active-low: ON => RESET, OFF => SET */
	HAL_GPIO_WritePin(Red_LED_GPIO_Port,   Red_LED_Pin,   red_on   ? GPIO_PIN_RESET : GPIO_PIN_SET);
	HAL_GPIO_WritePin(Green_LED_GPIO_Port, Green_LED_Pin, green_on ? GPIO_PIN_RESET : GPIO_PIN_SET);
	HAL_GPIO_WritePin(Blue_LED_GPIO_Port,  Blue_LED_Pin,  blue_on  ? GPIO_PIN_RESET : GPIO_PIN_SET);
}

/* Returns the highest cell voltage across the connected cells (uV). */
static uint32_t LED_Highest_Cell_Voltage(void) {
	uint8_t cells = Get_Number_Of_Cells();
	uint32_t highest = 0;
	if (cells == 0) {
		return 0;
	}
	for (uint8_t i = 0; i < cells; i++) {
		uint32_t v = Get_Cell_Voltage(i);
		if (v > highest) {
			highest = v;
		}
	}
	return highest;
}

void vLED_Blinky(void const *pvParameters) {
	TickType_t xDelay = 500 / portTICK_PERIOD_MS;

	LED_Set(0, 0, 0);          /* all off at start */
	vTaskDelay(xDelay * 4);

	for (;;) {

		uint32_t error = Get_Error_State();

		if (error != 0) {
			/* ERROR: all three colours on (white), then a burst of red
			 * flashes whose count encodes the error value, like the
			 * original firmware. */
			LED_Set(1, 1, 1);
			for (uint32_t i = 0; i < error; i++) {
				vTaskDelay(200 / portTICK_PERIOD_MS);
				LED_Set(0, 1, 1);              /* red off, others stay on */
				vTaskDelay(200 / portTICK_PERIOD_MS);
				LED_Set(1, 1, 1);              /* red back on */
			}
			vTaskDelay(xDelay * 4);
			continue;
		}

		/* Are we actively charging? Needs the pack connected and the
		 * regulator reporting charge in progress. */
		uint8_t charging = (Get_Balance_Connection_State() == CONNECTED)
		                && (Get_Regulator_Charging_State() == 1);

		if (charging) {
			uint32_t vcell = LED_Highest_Cell_Voltage();

			if (vcell >= LED_CELL_HIGH_THRESH_UV) {
				LED_Set(0, 1, 0);             /* HIGH  -> green  */
			}
			else if (vcell >= LED_CELL_LOW_THRESH_UV) {
				LED_Set(1, 1, 0);             /* MED   -> yellow */
			}
			else {
				LED_Set(1, 0, 0);             /* LOW   -> red    */
			}
		}
		else {
			/* Idle / not charging -> LED off */
			LED_Set(0, 0, 0);
		}

		vTaskDelay(xDelay);
	}
}

/* printf output sink.
 *
 * IMPORTANT: On this board there is no USB-UART adapter attached, so the
 * UART DMA TX-complete callback that clears sUart_tx_ready may never fire.
 * The original UART_Transfer() spins on `while (sUart_tx_ready != 1);`,
 * which hangs the CALLING task forever the first time it prints. Because
 * every printf() in the firmware funnels through _putchar(), that single
 * blocking wait was enough to freeze the ADC task mid-printf and stall PD
 * message processing (confirmed via the UCPD ISR firing on top of a stuck
 * UART_Transfer in the call stack).
 *
 * Fix: route printf through a NON-BLOCKING transmit. If the UART isn't
 * draining, characters are simply dropped instead of hanging the task.
 * Serial console output still works normally once an adapter is attached
 * and the TX-complete IRQ starts clearing the ready flag.
 */
void _putchar(char character) {
	/* Fire-and-forget: attempt a single non-blocking HAL UART transmit.
	 * If the peripheral is busy or nothing is draining it, drop the byte.
	 * Never wait on sUart_tx_ready here. */
	extern UART_HandleTypeDef huart1;
	(void)HAL_UART_Transmit(&huart1, (uint8_t *)&character, 1, 0);
}

/* Called by FreeRTOS (configCHECK_FOR_STACK_OVERFLOW == 2) the moment any
 * task overruns its stack. Instead of silently corrupting the kernel lists
 * and HardFaulting with a garbage PC, we stop here so the offending task is
 * identifiable in the debugger via pcTaskName / xTask. */
void vApplicationStackOverflowHook(TaskHandle_t xTask, char *pcTaskName)
{
	(void)xTask;
	(void)pcTaskName;   /* <-- inspect this in the debugger to see which task */
	taskDISABLE_INTERRUPTS();
	for (;;) { }
}

/* Called if a FreeRTOS heap allocation (task/queue creation) fails. */
void vApplicationMallocFailedHook(void)
{
	taskDISABLE_INTERRUPTS();
	for (;;) { }
}

/* USER CODE END 4 */

/* USER CODE BEGIN Header_StartDefaultTask */
/**
 * @brief  Function implementing the defaultTask thread.
 * @param  argument: Not used
 * @retval None
 */
/* USER CODE END Header_StartDefaultTask */
void StartDefaultTask(void const * argument)
{

  /* USER CODE BEGIN 5 */
	/* Infinite loop */
	for (;;) {
		osDelay(1);
	}
  /* USER CODE END 5 */ 
}

/**
  * @brief  Period elapsed callback in non blocking mode
  * @note   This function is called  when TIM1 interrupt took place, inside
  * HAL_TIM_IRQHandler(). It makes a direct call to HAL_IncTick() to increment
  * a global variable "uwTick" used as application time base.
  * @param  htim : TIM handle
  * @retval None
  */
void HAL_TIM_PeriodElapsedCallback(TIM_HandleTypeDef *htim)
{
  if (htim->Instance == TIM1) {
    HAL_IncTick();
    extern void USBPD_DPM_TimerCounter(void);
    USBPD_DPM_TimerCounter();
  }
}

/**
  * @brief  This function is executed in case of error occurrence.
  * @retval None
  */
void Error_Handler(void)
{
  /* USER CODE BEGIN Error_Handler_Debug */
	/* User can add his own implementation to report the HAL error return state */

  /* USER CODE END Error_Handler_Debug */
}

#ifdef  USE_FULL_ASSERT
/**
  * @brief  Reports the name of the source file and the source line number
  *         where the assert_param error has occurred.
  * @param  file: pointer to the source file name
  * @param  line: assert_param error line source number
  * @retval None
  */
void assert_failed(uint8_t *file, uint32_t line)
{ 
  /* USER CODE BEGIN 6 */
	/* User can add his own implementation to report the file name and line number,
	 tex: printf("Wrong parameters value: file %s on line %d\r\n", file, line) */
  /* USER CODE END 6 */
}
#endif /* USE_FULL_ASSERT */

/************************ (C) COPYRIGHT STMicroelectronics *****END OF FILE****/

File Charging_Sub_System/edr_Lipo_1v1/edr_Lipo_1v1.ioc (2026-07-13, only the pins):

Mcu.UserName=STM32G071CBTx
PA0.GPIO_Label=Cell_4S_ADC
PA0.Signal=ADC1_IN0
PA1.GPIO_Label=Cell_3S_ADC
PA1.Signal=ADC1_IN1
PA10.Signal=USART1_RX
PA13.Signal=SYS_SWDIO
PA14-BOOT0.Signal=SYS_SWCLK
PA2.GPIO_Label=Cell_2S_ADC
PA2.Signal=ADC1_IN2
PA3.GPIO_Label=Cell_1S_ADC
PA3.Signal=ADC1_IN3
PA4.GPIO_Label=BAT_ADC
PA4.Signal=ADC1_IN4
PA5.GPIO_Label=Blue_LED
PA5.Signal=GPIO_Output
PA7.GPIO_Label=Green_LED
PA7.Signal=GPIO_Output
PA9.Signal=USART1_TX
PB0.GPIO_Label=EN_OTG
PB0.Signal=GPIO_Output
PB1.GPIO_Label=PROTCHOT
PB1.Signal=GPIO_Input
PB11.GPIO_Label=ILIM_HIZ
PB11.Signal=GPIO_Output
PB12.GPIO_Label=CHRG_OK
PB12.Signal=GPIO_Input
PB2.GPIO_Label=Red_LED
PB2.Signal=GPIO_Output
PB4.GPIO_Label=CELL_1S_DIS_EN
PB4.Signal=GPIO_Output
PB5.GPIO_Label=CELL_2S_DIS_EN
PB5.Signal=GPIO_Output
PB6.Signal=I2C1_SCL
PB7.Signal=I2C1_SDA
PB8.GPIO_Label=CELL_3S_DIS_EN
PB8.Signal=GPIO_Output
PB9.GPIO_Label=CELL_4S_DIS_EN
PB9.Signal=GPIO_Output
PD0.Signal=UCPD2_CC1
PD1.Signal=UCPD2_DBCC1
PD2.Signal=UCPD2_CC2
PD3.Signal=UCPD2_DBCC2

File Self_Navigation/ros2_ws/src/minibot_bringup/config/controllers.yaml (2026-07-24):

# =============================================================================
#  controllers.yaml -- ros2_control controller_manager
#
#  LOADED BY   minibot_bringup/robot.launch.py -> ros2_control_node
#
#  ALL LIMITS ARE GENERATED from robot.yaml by tools/generate_config.py.
#
#  ##### REVISION 2 -- MEASURED HARDWARE #####
#  Rev 1 used wheel_radius 0.190 / wheel_separation 0.300. BOTH WRONG.
#  DERIVED FROM: wheel_radius 0.0336 (67.2 mm dia), wheel_separation 0.400, 5-20 RPM
#     v_max = 0.0704 m/s   omega_max = 0.3519 rad/s   a_max = 0.1407 m/s^2
#     180 deg spin in place = 8.93 SECONDS
# =============================================================================

controller_manager:
  ros__parameters:
    update_rate: 50   # Hz -- matches the STM32's 50 Hz feedback frame rate

    joint_state_broadcaster:
      type: joint_state_broadcaster/JointStateBroadcaster

    diff_drive_controller:
      type: diff_drive_controller/DiffDriveController

diff_drive_controller:
  ros__parameters:
    left_wheel_names: ["left_wheel_joint"]
    right_wheel_names: ["right_wheel_joint"]

    # -------------------------------------------------------------------------
    #  THE TWO MOST IMPORTANT NUMBERS ON THE ROBOT.
    #    wheel_radius     -> every DISTANCE the robot believes it moved
    #    wheel_separation -> every ANGLE the robot believes it turned
    #  Measure them. Calibrate them (scripts/calibrate_odom.py). Then trust them.
    # -------------------------------------------------------------------------
    #  wheel_radius     -> every DISTANCE the robot believes it moved
    #  wheel_separation -> every ANGLE  the robot believes it turned
    #
    #  MEASURE wheel_radius LOADED (robot's weight on the wheel). Rubber
    #  compresses ~1 mm, and 1 mm on a 33.6 mm radius is a 3% odometry error
    #  that compounds over an entire cleaning run.
    #
    #  Rev 1 had these as 0.190 / 0.300 -- a 5.65x and a 33% error respectively.
    wheel_separation: 0.400
    wheel_radius: 0.0336

    wheel_separation_multiplier: 1.0
    left_wheel_radius_multiplier: 1.0
    right_wheel_radius_multiplier: 1.0

    publish_rate: 50.0
    odom_frame_id: odom
    base_frame_id: base_link

    # Step-count odometry is EXCELLENT in x (we counted every pulse) and MEDIOCRE
    # in yaw (a ruler-measured wheel_separation goes straight into heading). Tell
    # the EKF that: small x variance, larger yaw variance. It then leans on the
    # gyro for heading, which is exactly what we want.
    pose_covariance_diagonal:  [0.001, 0.001, 0.001, 0.001, 0.001, 0.03]
    twist_covariance_diagonal: [0.001, 0.001, 0.001, 0.001, 0.001, 0.03]

    # false -> use the STM32's ACTUAL emitted step counts (which include whatever
    # the jerk-limited profile really did during transients), not the commanded
    # velocity. Open-loop integration of the command would drift every time Nav2
    # asked for something the profile could not instantly deliver.
    open_loop: false

    # false -> robot_localization's EKF owns odom -> base_link.
    # TWO publishers on one TF edge = the robot flickers between two poses.
    enable_odom_tf: false

    cmd_vel_timeout: 0.5

    # ---- kinematic envelope (20 RPM cap) ----
    linear.x.has_velocity_limits: true
    linear.x.has_acceleration_limits: true
    linear.x.has_jerk_limits: false
    linear.x.max_velocity: 0.0704
    linear.x.min_velocity: -0.0704
    linear.x.max_acceleration: 0.1407
    linear.x.max_jerk: 0.0
    linear.x.min_jerk: 0.0

    angular.z.has_velocity_limits: true
    angular.z.has_acceleration_limits: true
    angular.z.has_jerk_limits: false
    angular.z.max_velocity: 0.3519
    angular.z.min_velocity: -0.3519
    angular.z.max_acceleration: 0.7037
    angular.z.min_acceleration: -0.7037
    angular.z.max_jerk: 0.0
    angular.z.min_jerk: 0.0

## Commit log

2026-05-15 remove PCB_Design from main
2026-05-15 fix EDR_LIPO submodule
    [Connectors_U_B.SchDoc, EDR_LIPO.PrjPcb, Main.SchDoc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]
2026-05-20 Remove old EDR_LIPO files
    [Connectors_U_B.SchDoc, EDR_LIPO.PrjPcb, Main.SchDoc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]
2026-05-20 Add PCB design files
2026-05-20 Fix: add PCB folders as regular directories
    [Connectors_U_B.SchDoc, EDR_LIPO.PrjPcb, EDR_Power_D.PrjPcb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]
2026-07-17 Add SFAMR_MainPCB to MAIN_CONTROLLER
    [PCB3.PcbDoc, PCB_main_SAFMR.PcbDoc, PcbLib2.PcbLib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]
2026-07-17 Update Charging_Sub_System/EDR_LIPO with board photos and renders
    [Connectors_U_B.SchDoc, EDR_LIPO.PrjPcb, Main.SchDoc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]
2026-07-17 Remove stray root-level EDR_LIPO; keep grouped copy in Charging_Sub_System
    [Connectors_U_B.SchDoc, EDR_LIPO.PrjPcb, Main.SchDoc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]
2026-07-17 Update Charging_Sub_System README with styled overview
2026-07-17 Update Charging_Sub_System README with all three photos and specs
2026-07-18 Remove merged folders from main
    [Connectors_U_B.SchDoc, EDR_LIPO.PrjPcb, EDR_Power_D.PrjPcb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]
2026-07-18 Add Charging_Sub_System with EDR_LIPO and edr_Lipo_1v1
    [Connectors_U_B.SchDoc, EDR_LIPO.PrjPcb, Main.SchDoc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]
2026-07-18 Add README to Charging_Sub_System
2026-07-24 Add navigation files to main
    [base.xacro, controllers.yaml, imu.xacro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]
2026-08-06 Create 3D Enclosure Design

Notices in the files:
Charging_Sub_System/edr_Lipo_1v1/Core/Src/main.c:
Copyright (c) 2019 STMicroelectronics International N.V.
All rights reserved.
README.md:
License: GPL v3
